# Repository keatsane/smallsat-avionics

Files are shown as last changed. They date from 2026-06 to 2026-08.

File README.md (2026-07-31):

# SmallSat Avionics SIL/HIL Testbed

A bench testbed for small-satellite avionics: STM32 firmware, portable C++ flight logic, and Python tooling for software- and hardware-in-the-loop testing.
Everything runs on a workbench with real parts and test gear: an STM32 as the flight computer, sensors and power hardware, a logic analyzer, and a scope. Behavior gets checked in software first (SIL), then on the hardware itself (HIL), and the results - logs, reports, and scope captures - land in the repo alongside the code.

## The stack
- STM32 firmware in C: bare-metal CMSIS drivers, timers, UART, sensors, watchdog.
- Flight logic in C++: spacecraft modes, fault detection, and safe-mode handling, written to run and be tested on a PC before reaching hardware.
- Python: test scenarios, fault injection, and report generation.

## Status
The mission loop works over radio, end to end: the vehicle - on bench power, no data cable - is commanded over a LoRa uplink into its pointing mode, captures an image, and downlinks it over a separate nRF24 payload link, where the ground station reassembles it and asks for whatever the air dropped. The lossy one-way payload link runs selective repeat: one full pass, then the ground names its missing chunks over the uplink and the vehicle resends exactly those out of the camera's own buffer.

The host flight software is unit-tested and runs a fourteen-scenario SIL suite: modes, faults, command validation, telemetry, recovery, degraded fallbacks, same-cycle response ordering, and closed-loop attitude scenarios against an in-repo plant model with measured inertias. The same C++ flight logic cross-compiles onto the STM32 behind a platform abstraction; the bare-metal side has SysTick timing, interrupt-driven UART across three USARTs, register-level SPI and I2C drivers for six devices, and the shared framed message codec in `common/protocol/`.

The OBC now runs a FreeRTOS task model rather than a super-loop: one control task owns the flight software at 10 Hz on an absolute wake-up, sensor sampling and health reporting run as their own tasks, and every task's state, check-in age, and stack high-water go out as telemetry at 1 Hz. An independent watchdog is serviced only when every task with a liveness deadline has checked in, and its bite has been demonstrated on the bench - the board resets and comes back reporting `reset=iwdg-watchdog`.

The first HIL slice is bench-verified: the board beacons live telemetry, the host runner detects link loss against the 5 s heartbeat timeout, and both HIL scenarios pass with scope-backed packet timing. The ICM-20948 IMU is also in the loop: accel/gyro plus AK09916 magnetometer samples go out as timestamped telemetry with per-half validity flags, and the sensor monitor turns invalid or frozen sources into the matching dropout faults. `ACCEL_GYRO_DROPOUT` is Degraded and can retreat POINTING/DETUMBLE to STANDBY; `MAG_DROPOUT` is a report-only Warning. INA228 power telemetry is live too - bus voltage, current, and power as timestamped, validity-flagged samples, sensed high-side on the main battery bus so the voltage reads state of charge; `POWER_DROPOUT` covers an invalid or missing sample. Structural temperature (TMP117) streams the same way, with overtemperature wired to SAFE and a report-only undertemperature.

The physical rig is built: a three-plate stack on a lazy-susan pivot, with the reaction wheel and its encoder below, the OBC and sensors in the middle, and the radios and status LEDs up top. The wheel runs closed-loop FOC against a real magnetic encoder, and stepping its speed visibly kicks the platform the other way - the reaction-wheel effect, on the bench. The whole stack runs off a 14.8 V bus through its own switch, shunt, and regulators.

The attitude layer runs on the platform even while the wheel's driver board is away for replacement: yaw comes from a gyro-integrated, magnetometer-anchored heading estimate (the compass self-calibrates its hard iron and even its sign, live, against the gyro), DETUMBLE enters autonomously when the platform is spun and hands back whatever mode it interrupted, and a commanded bearing survives mode changes. The ground segment is its own node: an Adafruit Feather M0 with both receivers and two OLED status panels, compiling the satellite's own protocol headers, bridged to a Python console that decodes, files images, retries commands until acknowledged, and can fly the whole point-shoot-downlink-park sequence as one `shoot` command.

Remaining: the wheel driver's replacement board (closing the physical control loop, with HIL for the attitude requirements), the battery and its fuse (removing the last wires entirely), and the slew-and-image survey capstone.

## Layout
- obc/ - on-board computer firmware, STM32F446 board support (drivers, devices, FreeRTOS tasks)
- common/ - the wire contract: frame codec, message layouts, and the command/fault/mode id catalog
- docs/ - the written record: architecture, requirements, verification, hardware, and reports
- esc/ - reaction-wheel node firmware, SimpleFOC on the B-G431B-ESC1
- fsw/ - portable C++ flight software: modes, faults, commands, attitude control, with host unit tests, the SIL shim, and the plant model
- gsw/ - ground station firmware for the Feather M0: both receivers, the uplink, and the OLED panels
- tools/ - host-side Python: the ground console, SIL and HIL scenario runners, scope capture, over a shared ground library
- cad/ - Fusion 360 models for the printed frame, plates, and flywheel
- vendor/ - CMSIS, FreeRTOS, and ETL as submodules, plus checked-in OV2640 register tables

## Documentation

| Document | What is in it |
| --- | --- |
| [architecture.md](docs/architecture.md) | how the system is put together: the language split, the two comm links, the onboard buses, the FDIR pipeline, and the three-plate stack |
| [requirements.md](docs/requirements.md) | every requirement with its id, status, verification method, and the artifact that proves it |
| [verification.md](docs/verification.md) | the evidence ladder, the SIL and HIL harnesses, and the full scenario catalog |
| [setup.md](docs/setup.md) | prerequisites, building and flashing each node, and every test and tooling command |
| [bom.md](docs/bom.md) | the parts actually on the bench, with a vendored datasheet block for each |
| [hardware.md](docs/hardware.md) | the physical build: part constraints, bench tools, placement and keep-away rules, and the CAD layout |
| [wiring.md](docs/wiring.md) | the bench wiring sheet - connector by connector, pin by pin |
| [roadmap.md](docs/roadmap.md) | a working document: what is left to build, in order, and the design decisions behind it |
| [journal.md](docs/journal.md) | a working document: the dated log of what was built each session and how it went |
| [reports/](docs/reports) | generated SIL and HIL run reports, plus the scope-capture companions |

## License
Apache 2.0.

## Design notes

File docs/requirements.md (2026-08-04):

# Requirements

Running requirements for the avionics stack. Each requirement has an ID, a statement, a status, and a verification method (test, analysis, inspection, or demonstration); once there is evidence, the artifact is listed too. Requirements are written ahead of the code they govern, so many start as planned until their phase lands. The status, not the existence of the requirement, tracks reality: planned -> in progress -> unit-verified -> SIL-verified -> bench-verified -> HIL-verified. A requirement whose verification line lists methods beyond its current status still owes that evidence.

| Section | Covers |
| --- | --- |
| [Mode management](#mode-management) | the six modes, the legal transitions between them, and the transition log |
| [Fault management](#fault-management) | the detect - debounce - latch - respond pipeline, severities, and the degraded fallbacks |
| [Executive](#executive) | the once-per-cycle ordering, including which side wins a same-cycle conflict |
| [Comms - command uplink and telemetry downlink](#comms---command-uplink-and-telemetry-downlink) | command validation and acknowledgment, the heartbeat, and the command-loss timer |
| [Real-time execution and recovery](#real-time-execution-and-recovery) | the fixed-rate control cycle, task health, stack margins, and the watchdog |
| [Sensors and data validity](#sensors-and-data-validity) | validity flags, staleness, and disagreement between redundant sources |
| [Status indication](#status-indication) | the three-bead WS2812 array - mode, fault severity, and link health |
| [Attitude control (ADCS)](#attitude-control-adcs) | detumble and pointing against the reaction wheel |
| [Payload](#payload) | image capture, the camera dropout fault, and the chunked downlink |
| [Platform abstraction and portability](#platform-abstraction-and-portability) | the boundary that lets the same flight software run on the host and on the STM32 |
| [Verification and traceability](#verification-and-traceability) | the scenario harnesses and the requirement-to-artifact chain |

## Mode management

The spacecraft operates in exactly one of six modes at any time. Their intent:

| Mode | Purpose |
| ---- | --- |
| BOOT | power-on and self-checks |
| STANDBY | idle and healthy, awaiting commands |
| DETUMBLE | reduce body rates after deployment or upset |
| POINTING | hold a commanded attitude |
| DOWNLINK | empty the onboard data buffer to the ground during a contact pass |
| SAFE | minimal, power-conservative state after a critical fault |

**REQ-MODE-001** - The flight software shall represent the current operating mode as exactly one value of the set {BOOT, STANDBY, DETUMBLE, POINTING, DOWNLINK, SAFE} at all times.  
**Type**: Functional  
**Status**: unit-verified  
**Verification**: unit test  
**Artifact**: fsw/test/test_mode_manager.cpp

**REQ-MODE-002** - On power-on or reset, the flight software shall initialize the current mode to BOOT before permitting any transition, and have an empty log.  
**Type**: Functional  
**Status**: unit-verified  
**Verification**: unit test  
**Artifact**: fsw/test/test_mode_manager.cpp

**REQ-MODE-003** - The flight software shall permit only the autonomous mode transitions listed below. Any transition not listed - including a transition from a mode to itself - shall be treated as illegal.

| From | Legal transitions to |
| ---- | --- |
| BOOT | STANDBY, DETUMBLE, SAFE |
| STANDBY | DETUMBLE, POINTING, DOWNLINK, SAFE |
| DETUMBLE | STANDBY, POINTING, DOWNLINK, SAFE |
| POINTING | STANDBY, DETUMBLE, DOWNLINK, SAFE |
| DOWNLINK | STANDBY, DETUMBLE, POINTING, SAFE |
| SAFE | none autonomously (ground-commanded to STANDBY only - see REQ-MODE-006) |

The operating modes form a clique - each reaches every other. An earlier table forced sequencing hops (STANDBY could not reach POINTING without passing through DETUMBLE), which encoded a deployment story this bench rig does not have and cost a command per hop. What stays restricted is the frame of the graph: BOOT is left only by passing self-checks, SAFE only by ground command.

**Type**: Functional  
**Status**: unit-verified  
**Verification**: unit test  
**Artifact**: fsw/test/test_mode_manager.cpp

**REQ-MODE-004** - On a request for a transition that is not in the legal set, the flight software shall leave the current mode unchanged and shall not append a transition log entry.  
**Type**: Functional  
**Status**: SIL-verified  
**Verification**: unit test and SIL  
**Artifact**: fsw/test/test_mode_manager.cpp, docs/reports/sil/SIL-007.md

**REQ-MODE-005** - Every operating mode (BOOT, STANDBY, DETUMBLE, POINTING, DOWNLINK) shall have a legal transition to SAFE, so a fault response can command SAFE from any operating mode.  
**Type**: Functional  
**Status**: unit-verified  
**Verification**: unit test  
**Artifact**: fsw/test/test_mode_manager.cpp

**REQ-MODE-006** - The flight software shall perform no autonomous transition out of SAFE. The only permitted exit from SAFE shall be a ground-commanded transition to STANDBY.  
**Type**: Functional  
**Status**: SIL-verified  
**Verification**: unit test and SIL  
**Artifact**: fsw/test/test_mode_manager.cpp, docs/reports/sil/SIL-006.md

**REQ-MODE-007** - The flight software shall record, for every transition, the trigger that caused it, drawn from the set {PowerOn, Nominal, FaultEntry, FaultCleared, Timeout, Command}.  
**Type**: Functional  
**Status**: unit-verified  
**Verification**: unit test  
**Artifact**: fsw/test/test_mode_manager.cpp

**REQ-MODE-008** - On every accepted transition, the flight software shall append one record to the mode transition log containing: the platform timestamp in milliseconds, the trigger, the previous mode, the new mode, and the requirement ID the transition serves.  
**Type**: Functional  
**Status**: unit-verified  
**Verification**: unit test  
**Artifact**: fsw/test/test_mode_manager.cpp

**REQ-MODE-010** - The flight software shall leave BOOT autonomously, entering STANDBY once every fault detector has had a full debounce window to disqualify the vehicle and none has latched a Critical fault. The transition shall carry the Nominal trigger. BOOT shall never be a resting state: absent a Critical fault the vehicle proceeds, and given one it safes.  
**Type**: Functional  
**Status**: unit-verified  
**Verification**: unit test and SIL  
**Artifact**: fsw/src/executive.cpp, fsw/test/test_executive.cpp

The wait is deliberate rather than an immediate hop on the first cycle. A fault needs `debounce_n` consecutive bad samples to latch, so leaving BOOT any sooner would mean declaring the self-check passed before a persistently bad sensor could possibly have failed it.

**REQ-MODE-011** - The flight software shall exit DETUMBLE autonomously, entering STANDBY once the measured body rate has remained inside the controller's deadband for one second of consecutive samples. The transition shall carry the Nominal trigger. A sample outside the deadband shall reset the count.
**Type**: Functional
**Status**: SIL-verified (SIL-013 - the vehicle nulls a 1 rad/s spin and steps down on its own, with the Nominal trigger and this requirement id in the log row. SIL-011 ends before the exit can fire and still expects DETUMBLE, so the pair pins both halves: converge first, then leave)
**Verification**: SIL, then HIL once the wheel is back
**Artifact**: fsw/src/executive.cpp, docs/reports/sil/SIL-013.md

**REQ-MODE-012** - The flight software shall enter DETUMBLE autonomously from any operating mode other than SAFE and POINTING when the measured body rate exceeds a configured threshold for three consecutive samples, shall remember the interrupted mode, and shall return to it when the detumble completes. The transitions shall carry the Nominal trigger.
**Type**: Functional
**Status**: SIL-verified (SIL-014 - a 2.5 rad/s shove in STANDBY pulls the vehicle into DETUMBLE on its own and it resumes STANDBY when nulled; the resume of an interrupted DOWNLINK is unit-verified. The shove has to beat bearing friction to the threshold, which sheds ~2.9 rad/s per second on its own - on this rig autonomy only sees the upsets friction cannot handle first)

**POINTING is excluded, and the rig is why (2026-08-04).** A slew to a new bearing is body rate on purpose, and it passes the entry threshold long before it reaches the target - so the vehicle interrupted its own manoeuvre, detumbled the rate its own controller had asked for, resumed POINTING, and started again. The bench showed forty seconds of that without ever arriving. The rule underneath: this requirement answers rate *nobody asked for*. In POINTING the rate is the controller's own output, and bounding it belongs to the pointing law's damping term, not to a mode change that discards the target. SAFE is excluded for the older reason - a safed vehicle sheds activity, and spinning quietly is what SAFE already accepts.
**Verification**: unit test, SIL, then HIL once the wheel is back
**Artifact**: fsw/src/executive.cpp, fsw/test/test_executive.cpp, docs/reports/sil/SIL-014.md

**REQ-MODE-009** - The mode transition log shall be a fixed-capacity buffer that allocates no memory dynamically and retains at least the 32 most recent records; when full, the oldest record shall be overwritten.  
**Type**: Constraint  
**Status**: unit-verified  
**Verification**: unit test  
**Artifact**: fsw/test/test_mode_manager.cpp

## Fault management

Every fault carries a severity that drives its response:

| Severity | Response when latched |
| --- | --- |
| Warning | reported in telemetry; off-nominal but still fully capable; no failover |
| Degraded | a capability was lost but a documented fallback exists; switch to it and keep operating; does not force SAFE |
| Critical | a capability was lost with no fallback; forces SAFE if unresolved |

The live fault catalog (command-link loss, IMU dropouts, power-monitor dropout, undervoltage, overvoltage, and overcurrent) is defined once in `common/protocol/state.hpp`; a fault's position there is both its id and its bit in the active-fault bitmask. Planned future capabilities add their own faults when the detector code lands.

**REQ-FAULT-001** - The fault manager shall latch an active fault until it is explicitly cleared; a condition that clears on its own shall not un-latch the fault.  
**Type**: Functional  
**Status**: unit-verified  
**Verification**: unit test  
**Artifact**: fsw/test/test_fault_manager.cpp

**REQ-FAULT-002** - A latched Critical fault shall command SAFE, and only after its debounce window so a transient sample cannot force it.  
**Type**: Functional  
**Status**: bench-verified (the bench supply was walked down from 14.8 V; UNDERVOLTAGE latched at 13.6 V and the vehicle entered SAFE within one heartbeat, with the mode and fault beads following)  
**Verification**: unit test, SIL scenario (undervoltage -> SAFE), then a bench sweep  
**Artifact**: fsw/test/test_fault_manager.cpp, docs/reports/sil/SIL-001.md (scenario SIL-001), docs/journal.md

**REQ-FAULT-003** - Each fault shall have a defined policy - severity, debounce threshold, and owning requirement - held in a single fault table that is the only place fault policy is written; a compile-time check shall keep that table sized to the fault catalog.  
**Type**: Constraint  
**Status**: unit-verified  
**Verification**: inspection and unit test (compile-time size check)  
**Artifact**: fsw/src/fault_manager.cpp

**REQ-FAULT-004** - A fault shall latch only after its debounce threshold of consecutive bad samples is reached; a single transient bad sample shall never latch it.  
**Type**: Functional  
**Status**: SIL-verified  
**Verification**: unit test and SIL  
**Artifact**: fsw/test/test_fault_manager.cpp, docs/reports/sil/SIL-004.md

**REQ-FAULT-005** - A fault of Warning or Degraded severity shall not by itself command SAFE; a Degraded fault shall switch to its documented fallback behavior (see Degraded fallback behaviors below), and every such fault shall be latched and reported in telemetry.
**Type**: Functional
**Status**: SIL-verified (SIL-003 for the no-SAFE half; SIL-009 and SIL-010 for the retreats. The WHEEL_DROPOUT retreat is unit-verified only - same code path from the same two modes as the gyro retreat, so a third scenario would restate SIL-009 with one name changed)
**Verification**: unit test and SIL  
**Artifact**: fsw/src/executive.cpp, fsw/src/sensor_monitor.cpp, fsw/test/test_fault_manager.cpp, fsw/test/test_executive.cpp, fsw/test/test_sensor_monitor.cpp, docs/reports/sil/SIL-003.md, docs/reports/sil/SIL-009.md, docs/reports/sil/SIL-010.md

### Degraded fallback behaviors

REQ-FAULT-005 requires a Degraded fault to switch to its documented fallback - listed below - rather than forcing SAFE. A Warning fault such as `MAG_DROPOUT` latches and reports without changing mode.

| Fault | Fallback when latched |
| ----- | --- |
| ACCEL_GYRO_DROPOUT | In POINTING or DETUMBLE - the modes that depend on body-rate feedback - retreat to STANDBY, a stable idle; holding attitude without the gyro is unsafe, but the loss is not mission-ending. In any other mode, latch and report only. |
| POWER_DROPOUT | In POINTING, DETUMBLE, or DOWNLINK - the high-power modes - retreat to STANDBY; with the power monitor unreadable, running power-hungry operations blind to brownout/overcurrent is unsafe, and STANDBY's lower draw cuts the risk. In any other mode, latch and report only. |
| WHEEL_DROPOUT | In POINTING or DETUMBLE - the two modes that actuate - retreat to STANDBY; with the reaction wheel's link down a torque command goes nowhere, so holding a mode the rig cannot fly is a false claim of control. In any other mode, latch and report only. |

The active retreats - POINTING/DETUMBLE -> STANDBY on ACCEL_GYRO_DROPOUT and on WHEEL_DROPOUT, and POINTING/DETUMBLE/DOWNLINK -> STANDBY on POWER_DROPOUT - run in the executive's fault-response step and are logged as `FaultEntry` transitions stamped REQ-FAULT-005. Recovery is ground-commanded like every fault (CLEAR_FAULT, REQ-FAULT-010); the planned RESET_DEVICE command will let the ground re-initialize the affected sensor before clearing it.

`WHEEL_DROPOUT` is detected from the silence on the wheel link rather than from a sample: the ESC beacons its status every 250 ms, so a second without one is a dead link. The first frame after boot gets a longer window (8 s) because the ESC aligns its FOC for about five seconds from cold and says nothing until it finishes - without that grace every boot would latch a dropout that clears itself a moment later, which is how a real fault gets trained into background noise. An ESC that never comes up still latches once the grace expires.

**REQ-FAULT-006** - The flight software shall evaluate the full fault set once per control cycle and apply the required response; when more than one response is indicated, the most conservative one shall win (SAFE dominates).  
**Type**: Functional  
**Status**: unit-verified  
**Verification**: unit test and SIL  
**Artifact**: fsw/test/test_fault_manager.cpp

**REQ-FAULT-007** - The flight software shall define the fault catalog once, in common/protocol/state.hpp, as a single index enum; a fault's position in that list shall be both its id and its bit position in the active-fault bitmask.  
**Type**: Interface  
**Status**: unit-verified  
**Verification**: inspection  
**Artifact**: common/protocol/state.hpp

**REQ-FAULT-008** - The set of currently latched faults shall be exposed as a bitmask (bit n set when fault id n is latched); this bitmask is what the heartbeat carries (see REQ-TLM-002).  
**Type**: Interface  
**Status**: unit-verified  
**Verification**: unit test  
**Artifact**: fsw/test/test_fault_manager.cpp

**REQ-FAULT-009** - A good (healthy) sample shall reset a fault's consecutive-bad-sample count, but shall not clear a fault that has already latched (see REQ-FAULT-001).  
**Type**: Functional  
**Status**: SIL-verified  
**Verification**: unit test and SIL  
**Artifact**: fsw/test/test_fault_manager.cpp, docs/reports/sil/SIL-004.md

**REQ-FAULT-010** - A latched fault shall be cleared only by an explicit action - a ground command or a defined recovery sequence - never autonomously by the flight software.  
**Type**: Functional  
**Status**: SIL-verified  
**Verification**: unit test and SIL  
**Artifact**: fsw/test/test_fault_manager.cpp, fsw/test/test_executive.cpp, docs/reports/sil/SIL-006.md

**REQ-FAULT-011** - The fault manager shall maintain a time-ordered log of fault state-change events; each entry shall record the platform timestamp, the fault id, and whether the fault latched or cleared. Only edges shall be logged - never per-sample - and the log shall be a fixed-capacity ring that overwrites its oldest entry when full.  
**Type**: Functional  
**Status**: unit-verified  
**Verification**: unit test  
**Artifact**: fsw/test/test_fault_manager.cpp

**REQ-FAULT-012** - It shall be possible to inhibit an individual fault's autonomous response for ground testing. An inhibited fault shall still debounce, latch, log, and report in telemetry; only the mode change it would command shall be suppressed. The inhibited set shall be reported, so that a run with inhibits in force cannot be mistaken for one without.  
**Type**: Functional  
**Status**: unit-verified (compile-time inhibit list declared at the platform boundary, announced in the boot banner, and carried in every heartbeat; ground-commandable inhibits wait on the ground station in Phase 8)  
**Verification**: unit test  
**Artifact**: fsw/src/fault_manager.cpp, fsw/src/executive.cpp, fsw/test/test_fault_manager.cpp, fsw/test/test_comms.cpp, common/protocol/msg.hpp, tools/ground/frames.py

Inhibits exist because the bench rig is routinely missing subsystems the flight configuration assumes: with no ground station, COMMAND_LINK_LOSS safes the vehicle about five seconds after every boot. Suppressing the *response* while keeping the *evidence* is the standard fault-protection inhibit used during spacecraft commissioning, and it is why the fault still appears in every heartbeat. WHEEL_DROPOUT was inhibited alongside it while the ESC was out of the stack; it came off on 2026-08-03 when the replacement board joined the link, which is the list working as intended - an inhibit is meant to be retired by hardware arriving, not to become permanent.

The inhibited set rides in the heartbeat as its own bitmask, in the same bit layout as the active-fault mask. Announcing it once in the boot banner is not enough: a console attached mid-run, or a log read later, shows two latched faults with the banner long out of scrollback and nothing on the wire saying their responses were suppressed. The status array distinguishes them by colour, but only to someone in the room. Carrying it in telemetry is what makes a saved log self-describing.

## Executive

**REQ-EXEC-001** - The flight software shall process each control cycle's inputs in a fixed, documented order: fault-sample ingestion, command validation, fault response, command dispatch. The fault response shall take precedence: a command accepted in the same cycle a critical fault forces SAFE shall not override the SAFE entry. Command acceptance acknowledges validation only; execution outcome is observed through telemetry. Validation is expected to reject what it can already determine is impossible, including an unreachable SET_MODE target (REQ-CMD-006) - what acceptance cannot promise is immunity from a fault response raised later in the same cycle.  
**Type**: Functional  
**Status**: SIL-verified  
**Verification**: unit test and SIL  
**Artifact**: fsw/src/executive.cpp, fsw/test/test_executive.cpp, docs/reports/sil/SIL-008.md

## Comms - command uplink and telemetry downlink

**REQ-CMD-001** - The flight software shall validate every command - known id, in-range parameters, and legal in the current mode - before acting on it; an invalid command shall be rejected and reported, never executed.  
**Type**: Functional  
**Status**: SIL-verified (the uplink path onto the OBC is written - both links are drained each cycle and decoded commands enter as cycle inputs - but has not been exercised on the bench, so validation remains host-only evidence)  
**Verification**: unit test and SIL  
**Artifact**: fsw/test/test_comms.cpp, obc/Src/main.cpp, tools/uart_monitor.py, docs/reports/sil/SIL-002.md (scenario SIL-002)

**REQ-CMD-002** - Loss of ground command contact for longer than a defined timeout shall raise COMMAND_LINK_LOSS.  
**Type**: Functional  
**Status**: SIL-verified  
**Verification**: unit test and SIL  
**Artifact**: fsw/test/test_comms.cpp, docs/reports/sil/SIL-005.md

**REQ-CMD-005** - BOOT shall not be a commandable mode. A SET_MODE request naming BOOT shall be rejected as a bad argument.  
**Type**: Functional  
**Status**: unit-verified  
**Verification**: unit test  
**Artifact**: fsw/src/comms/command_handler.cpp, fsw/test/test_comms.cpp

**REQ-CMD-006** - A SET_MODE request naming a mode that is not reachable from the current mode shall be rejected as illegal-in-mode at validation, rather than accepted and then refused by the mode manager.  
**Type**: Functional  
**Status**: SIL-verified  
**Verification**: unit test and SIL  
**Artifact**: fsw/src/comms/command_handler.cpp, fsw/test/test_comms.cpp, docs/reports/sil/SIL-007.md

This extends REQ-CMD-005's reasoning from one mode to the whole transition table: an acknowledgement that says yes while the vehicle does not move is a worse interface than a refusal that names why. It narrows REQ-EXEC-001 rather than contradicting it - acceptance still is not execution, because a safing raised in the same cycle overrides an accepted command (SIL-008). What changed is that a refusal already knowable at validation time is now reported at validation time.

BOOT means "powered on and still self-checking" - a state the vehicle enters by resetting and leaves by passing its checks (REQ-MODE-010). There is nothing for the flight software to do with a request to re-enter it. Validating it away matters because the alternative is worse than useless: `BOOT` is a real mode id and a legal transition target from nowhere, so without this check the command passes validation, is acknowledged as accepted, and then changes nothing - an ack that says yes while the vehicle does not move.

**REQ-CMD-003** - Every command shall be acknowledged in telemetry as accepted or rejected, with a reason given on rejection. A command repeating the previous sequence number shall be answered with the previous verdict and shall not be executed again.  
**Type**: Functional  
**Status**: SIL-verified (both verdicts observed as decoded telemetry frames; the retransmission rule is unit-verified. HIL still owed)  
**Verification**: unit test (ack construction, retransmission), SIL and HIL  
**Artifact**: fsw/test/test_comms.cpp, docs/reports/sil/SIL-002.md (scenario SIL-002)

The retransmission rule exists because the ground resends: the LoRa link is half duplex, the vehicle cannot hear anything while its own beacon is on the air, and a command sent into that window is simply not received. The ground console retransmits until it sees an ack, which means a command whose *ack* was lost arrives twice - so the vehicle answers the second copy without acting on it.

**REQ-CMD-004** - Every handled command shall be appended to a command event log recording the platform timestamp, the command id, the verdict, and the rejection reason. The log shall be a fixed-capacity ring that allocates no memory dynamically and overwrites its oldest entry when full.  
**Type**: Functional  
**Status**: unit-verified  
**Verification**: unit test  
**Artifact**: fsw/test/test_comms.cpp

**REQ-TLM-001** - All telemetry shall be framed with a sync header, message id, length, and CRC-16; a corrupted or mis-framed packet shall be detected and discarded, never acted on.  
**Type**: Interface  
**Status**: HIL-verified (live framing on the real wire, every frame CRC-checked with zero rejects over the window; the discard path itself is unit-verified)  
**Verification**: unit test and HIL  
**Artifact**: common/protocol/frame.cpp, fsw/test/test_comms.cpp, docs/reports/hil/HIL-001.md, docs/reports/hil/HIL-001-scope.md

**REQ-TLM-002** - The flight software shall emit a periodic heartbeat carrying uptime, a sequence number, the current mode, and the active-fault bitmask.  
**Type**: Functional  
**Status**: HIL-verified (1 Hz emission decoded live from the STM32 and timed on the scope; the on-wire frame carries real mode and fault state)  
**Verification**: unit test, SIL and HIL  
**Artifact**: fsw/test/test_comms.cpp, docs/reports/sil/SIL-001.md, docs/reports/hil/HIL-001.md, docs/reports/hil/HIL-001-scope.md

**REQ-TLM-003** - The heartbeat sequence number shall increment monotonically so the ground can detect dropped packets.  
**Type**: Functional  
**Status**: HIL-verified (59 consecutive live periods with zero gaps; a board reset is detected as a sequence discontinuity in HIL-002)  
**Verification**: unit test; demonstration (scope/host decode)  
**Artifact**: fsw/test/test_comms.cpp, docs/reports/hil/HIL-001.md, docs/reports/hil/HIL-002.md

**REQ-TLM-004** - The telemetry transport shall be swappable behind the frame format - UART first, radio later - with no change to the wire format.  
**Type**: Constraint  
**Status**: demonstrated untethered (2026-07-30 - the vehicle on bench power with no data cable attached: commanded into POINTING over LoRa, a capture and a downlink over the nRF24, 137 chunks reassembled to `captures/image_0017.jpg` with intact JPEG markers. The first pass delivered 72% and two selective-repeat rounds named and refilled the rest, which is the point of the protocol: delivery variance stopped mattering. One encoded frame crosses four transports unchanged; LoRa carries heartbeats, acks and attitude only - the full stream would want 2.8 s of air time per second)
**Verification**: inspection and HIL  
**Artifact**: common/protocol/frame.cpp (the format, unchanged per transport), fsw/platform/stm32/platform_stm32.cpp (one call, three transports), obc/Src/devices/rfm95.c, obc/Src/freertos/telemetry_task.cpp, obc/Src/drivers/uart.c

**REQ-TLM-006** - The ground shall be able to request a single frame of a named telemetry kind over the low-rate link. The full sensor stream shall not ride that link.
**Type**: Functional
**Status**: demonstrated over the air (2026-07-31 - `poll POWER` from the ground console returned one POWER frame over the beacon, on battery power with no cable: bus 16.68 V, 108 mA. The stream restriction is arithmetic: the full stream wants ~2.8 s of air time per second of flight)
**Verification**: unit test, then demonstration over the radio
**Artifact**: fsw/src/executive.cpp, fsw/test/test_executive.cpp, obc/Src/freertos/telemetry_task.cpp

**REQ-TLM-005** - The spacecraft shall indicate current mode, worst latched fault severity with a count of latched faults, and command-link state on a local status display, carrying the same information as the heartbeat packet so the two can be read against each other.  
**Type**: Functional  
**Status**: bench-verified (2026-07-30 - two faults latched and inhibited, the bead held blue and winked twice per cycle against a heartbeat naming exactly those two. Inhibited faults are counted: they are latched, which is what the requirement asks)  
**Verification**: demonstration (drive each mode, latch faults of each severity, and drop the uplink; observe the display against the decoded heartbeat)  
**Artifact**: obc/Src/freertos/control_task.cpp, obc/Src/devices/ws2812.c

## Real-time execution and recovery

**REQ-RT-001** - The flight software shall maintain a monotonic millisecond time base, used to timestamp every logged event.  
**Type**: Performance  
**Status**: bench-verified  
**Verification**: demonstration and inspection  
**Artifact**: obc/Src/drivers/systick.c, obc/Src/freertos/control_task.cpp (passes millis into each cycle)

**REQ-RT-002** - The decision paths shall run at a fixed, bounded rate and shall allocate no memory dynamically (fixed-capacity containers only).  
**Type**: Constraint  
**Status**: HIL-verified (HIL-003: 59 heartbeat periods, mean 1.000 s, the spread host-side USB jitter. The super-loop it replaced was a structural 2% slow. The rate held through a 128-chunk downlink with no cycle overrunning - the worst is the one a capture completes on, where the JPEG end-marker scan costs ~16 ms of 100. Static allocation only)  
**Verification**: inspection and analysis, plus HIL (measure heartbeat spacing idle and under downlink load)  
**Artifact**: fsw/include/fsw/inputs.hpp and fsw/include/fsw/fault_manager.hpp (fixed-capacity ETL containers, no heap), `configSUPPORT_DYNAMIC_ALLOCATION 0` in obc/Inc/FreeRTOSConfig.h, the control task's `xTaskDelayUntil` in obc/Src/freertos/control_task.cpp, docs/reports/hil/HIL-003.md

**REQ-RT-003** - Under concurrent workloads the flight software shall run as prioritized tasks with the control loop at the highest priority, and shall report task health (liveness and stack high-water).  
**Type**: Performance  
**Status**: HIL-verified (HIL-003, 60 s untouched: every task present in all 60 reports, watchdog fed on all of them, worst stack margin 104 free words against a 64 floor. Stacks are sized at ~2.5x measured peaks - generous rather than tight, because the kernel's high-water figure counts a fill pattern and reads optimistic when a written byte happens to hold it)  
**Verification**: HIL (scheduler-smoke run)  
**Artifact**: the task table in obc/Inc/rtos_tasks.h; obc/Src/freertos/; `task_health_t` in common/protocol/msg.hpp; docs/reports/hil/HIL-003.md
**Artifact**: the task table in obc/Inc/rtos_tasks.h; obc/Src/freertos/; `task_health_t` in common/protocol/msg.hpp with its ground decoder and 6 pytest cases

**REQ-RT-004** - An unhandled processor fault exception (hard fault, memory-management, bus, or usage fault) shall be caught by a dedicated handler that captures the fault context and performs a controlled reset, rather than leaving the processor halted in a default infinite loop.  
**Type**: Functional  
**Status**: bench-verified (forced a fault on the bench with a `udf` undefined instruction; the handler dumped pc=0x0800320c, CFSR=0x00010000 (UFSR.UNDEFINSTR) and HFSR=0x40000000 (FORCED - escalated to HardFault), then rebooted via NVIC_SystemReset, the next boot reading reset=software)  
**Verification**: demonstration (trigger a fault, observe the capture then reset)  
**Artifact**: obc/Src/drivers/fault.c

**REQ-WDG-001** - An independent hardware watchdog shall reset the on-board computer if the flight software stops servicing it within the watchdog window.  
**Type**: Functional  
**Status**: HIL-verified (service: HIL-003 fed the watchdog in all 60 reports of a 60 s window, each gated on every deadline task checking in. Bite: withholding the control task's check-in reset the board, and the next banner read `reset=iwdg-watchdog`. The withheld pet appears in telemetry first, which is what makes the reset attributable)
**Verification**: HIL (demonstrated reset)  
**Artifact**: obc/Src/drivers/iwdg.c, obc/Src/freertos/health_task.cpp

**REQ-WDG-002** - After any reset the flight software shall report the reset cause - including a watchdog reset - in a boot telemetry packet.  
**Type**: Functional  
**Status**: bench-verified (2026-07-30 - a cold start emitted exactly one `BOOT t=1125 ms reset=POWER_ON clk=180000000 Hz` frame, decoded from the packet rather than read off the banner. It crosses the PAL as a first-cycle input, not a side channel. Pin reset and watchdog reset were each demonstrated on the banner)  
**Verification**: HIL  
**Artifact**: obc/Src/drivers/reset.c, obc/Inc/drivers/reset.h, obc/Src/freertos/control_task.cpp, common/protocol/msg.hpp, tools/ground/frames.py

## Sensors and data validity

**REQ-SNS-001** - Every sensor sample shall be tagged with an acquisition timestamp and a validity flag; the flight software shall never use a sample marked invalid.  
**Type**: Functional
**Status**: bench-verified (the IMU sample carries an acquisition timestamp and per-half validity flags, streaming live on the bench; the sensor monitor treats an invalid half as a dropout rather than consuming it - a full attitude consumer that honors the flag lands with ADCS)
**Verification**: unit test and HIL
**Artifact**: common/protocol/msg.hpp (imu_data_t), obc/Src/devices/icm20948.c, fsw/src/sensor_monitor.cpp, fsw/test/test_sensor_monitor.cpp

**REQ-SNS-002** - A sensor whose data is invalid, missing, or frozen beyond a defined staleness window shall raise that sensor's dropout fault.
**Type**: Functional
**Status**: unit-verified (dropouts raised on invalid or frozen sources. Both invalid-source paths are bench-exercised: pulling the IMU latches ACCEL_GYRO_DROPOUT + MAG_DROPOUT, and POWER_DROPOUT latched while the INA228 was unreachable. **Owed: HIL**)
**Verification**: unit test and HIL
**Artifact**: fsw/src/sensor_monitor.cpp, fsw/test/test_sensor_monitor.cpp

**REQ-SNS-003** - Where redundant sources exist, disagreement beyond a defined threshold shall raise a dedicated disagreement fault added with that redundant sensor path.  
**Type**: Functional  
**Status**: deferred - conditional, and its condition is not met. The requirement is written to fire "where redundant sources exist" and this build has none: one IMU, one power monitor, one temperature sensor, one camera. Deliberately kept rather than deleted, because it is the rule any second sensor arrives under; deliberately not "planned", because planned implies work is queued and nothing here is buildable until a redundant path exists.  
**Verification**: unit test and SIL, when a redundant path exists

**REQ-SNS-004** - A valid monitored power reading outside its configured operating limits shall raise the corresponding power fault (undervoltage, overvoltage, overcurrent).
**Type**: Functional
**Status**: unit-verified; **HIL not planned** (2026-08-04). Each power fault is raised when its reading crosses the configured limit after debounce. An earlier bench run latched UNDERVOLTAGE live against the low-side monitor, but it has since moved high-side onto the 14.8 V bus and the limits were retuned, so that evidence does not cover this build.

Re-running it was considered and declined, for reasons worth stating rather than leaving as a gap. **Overcurrent cannot be tested at all here**: tripping 1.5 A needs a load bank the bench does not have, and the vehicle's own draw never approaches it. **Undervoltage and overvoltage would require disconnecting the flight battery and rigging a variable supply in its place**, which is bench work with a real chance of disturbing a rig that currently flies. The fault logic itself is exercised every run by the unit suite and by SIL-001, which drives an undervoltage to SAFE; what is missing is only the ADC-to-fault path on this specific wiring, and that is a narrower claim than the requirement being unverified.
**Verification**: unit test and HIL
**Artifact**: fsw/src/sensor_monitor.cpp, fsw/test/test_sensor_monitor.cpp

**REQ-SNS-005** - A valid monitored temperature reading outside its configured operating limits shall raise the corresponding temperature fault (overtemperature, undertemperature).
**Type**: Functional
**Status**: unit-verified; **HIL not planned** (2026-08-04). Both crossings latch after debounce, TEMP_DROPOUT on an invalid sample. Overtemperature is Critical -> SAFE; undertemperature is a report-only Warning, since a low-power state would only cool the spacecraft further.

Forcing a real crossing means heating the TMP117 to 60 C while it sits on a plate of PLA next to the flight electronics. A heat gun does that to more than the sensor, and risking a working vehicle to demonstrate a threshold comparison the unit tests already cover is a poor trade. Declined deliberately rather than left owed.
**Verification**: unit test and HIL
**Artifact**: fsw/src/sensor_monitor.cpp, fsw/test/test_sensor_monitor.cpp

## Status indication

**REQ-HMI-001** - The spacecraft shall indicate its current mode, the worst active fault severity, and its command-link health on an external visual indicator, updated every control cycle and readable without a ground connection.  
**Type**: Functional  
**Status**: bench-verified (three WS2812 beads from PA8 by TIM1_CH1 + DMA: mode by colour, the fault ladder, and the uplink as blinking amber before first contact, green in contact, red past the 5 s timeout. Bit timing scope-confirmed at 0.4/0.8 us on a 1.25 us period)
**Verification**: demonstration (observe the array follow a commanded mode change and a latched fault)  
**Artifact**: obc/Src/drivers/pwm_dma.c, obc/Src/devices/ws2812.c, obc/Src/main.cpp, docs/journal.md (the dated observation)

### Mode bead colors

Bead 0 carries the mode, one color each, no blinking - a spinning platform is read at a glance and a blink code is not.

**Motion is deliberately rationed across the strip.** Bead 1 spends it on a number (the latched-fault count) and bead 2 spends it on one persistent state (never-acquired). Nothing else blinks, and that is a decision rather than an omission: a strip where every bead moves cannot be counted, and the count is the only thing here carrying data rather than a category. DOWNLINK was considered for a mode blink and rejected - since the payload downlink became self-pacing a whole image leaves in about a second, so the blink would be over before anyone looked up.

| Mode | Color |
| ---- | ----- |
| BOOT | white |
| STANDBY | green |
| DETUMBLE | blue |
| POINTING | cyan |
| DOWNLINK | magenta |
| SAFE | red |

Bead 2 carries the uplink in three states: **blinking amber** before any command has ever arrived, **green** once the ground is in contact, **red** once the link has been silent past its 5 s timeout. Amber is a real distinction rather than a hedge - an un-latched loss fault before first contact only means the dead-man timer has not expired yet, which is unknown, not healthy - and it blinks because it is a state the rig sits in for a whole session, where a slow blink reads as searching and a steady amber reads as something settled.

**The bead asks the link, not the fault's response** (corrected 2026-07-30). It used to read `response_active(COMMAND_LINK_LOSS)`, which is false while the fault is inhibited - and the bench build inhibits it. The effect was that the bead went green on the first command ever received and stayed green for the rest of the session however long the ground had been gone. Suppressing a response is a decision about safing and says nothing about the link, so the display asks `link_lost()` directly. There is deliberately no fourth state for "silent but still inside the timeout": nothing keeps the link alive between typed commands, so that would be the normal condition during ordinary bench use and would blink continuously.

The whole array runs at level 4 of 255. The beads sit behind printed plastic and bleed through the walls at anything brighter, and 4 is the floor: the mixed colors set one channel to a fraction of it, and below that there are not enough steps left to hold the hue.

### Fault bead ladder

Bead 1 shows the worst rung that applies, highest first:

| Rung | Color | Meaning |
| ---- | ----- | --- |
| Critical | red | a latched Critical fault whose response is live - the vehicle is safing or has safed |
| Degraded | orange | a latched Degraded fault - a capability was lost and a documented fallback is in force |
| Warning | yellow | a latched Warning fault - off-nominal, reported only |
| Inhibited | blue | something is latched but every latched fault has its response inhibited (REQ-FAULT-012) |
| Clean | off | nothing latched |

An inhibited fault is deliberately excluded from the three alarm rungs and collected into the one below them. It remains in the heartbeat and in the boot banner, so nothing is hidden - but a bench build routinely runs with subsystems absent, and letting those hold the bead red on every boot is how a red indicator stops carrying information. Blue sits outside the red/orange/yellow alarm family on purpose: it reads as status, not as a call to act.

## Attitude control (ADCS)

**REQ-ADCS-001** - In DETUMBLE the flight software shall command the reaction wheel to reduce the measured body rate below a defined threshold.  
**Type**: Functional  
**Status**: **working on the rig (2026-08-04)** - a hand-spun platform pulls itself into DETUMBLE, the rate collapses to the deadband, and the vehicle steps back out on its own, repeatably and over the radio. Torques sit at 8-9 mN m against the 50 mN m ceiling. SIL-011 nulls a 2 rad/s spin in the model. Proportional rate feedback, no integral: against stiction an integral winds up while the platform is stuck and overshoots when it breaks loose.

The gain is the rig's, not the model's. At the modelled 0.02 N m per rad/s the loop commanded more torque than the bearing's breakaway and kicked the platform loose in alternating directions - a stick-slip limit cycle at ~90 deg/s that the model never showed, because the model's breakaway friction was a guess. 0.008 is what the bench accepts.

**The controller does about two and a half times what friction does (A/B, 2026-08-04).** "It stopped" is not proof on a platform that stops itself, so the same spin was run twice at 10 Hz on the wired link: in SAFE, where no torque is commanded and autonomous entry is disabled, and in STANDBY, where the spin pulls the vehicle into DETUMBLE. Both runs are checked in under `docs/data/` and graded by `tools/overlay.py`, which measures the arrest - the last unbroken run of falling rate - rather than the whole window, because a hand-spun run has a plateau in it while the platform is still being pushed and averaging that in halves the answer.

Friction alone shed the rate at **161 deg/s^2**; with the controller, **412 deg/s^2**. The peak commanded torque was 13 mN m, which against the measured platform inertia predicts ~164 deg/s^2 of additional deceleration against the ~250 observed - consistent within what an unmeasured `kOhmsPerKt` can account for, and pointing the same way as every other estimate of it. The measurement needs the control-rate telemetry: at the heartbeat's 1 Hz the whole decay is a single sample.  
**Verification**: SIL (single-axis plant model) and HIL (reaction-wheel rig)  
**Artifact**: fsw/src/attitude_control.cpp, fsw/test/test_attitude_control.cpp, fsw/sil/plant.cpp, fsw/sil/scenarios/sil_011_detumble.yaml, docs/reports/sil/SIL-011.md

**REQ-ADCS-002** - In POINTING the flight software shall hold a commanded single-axis attitude within a defined error band.  
**Type**: Functional  
**Status**: **working on the rig for small slews (2026-08-04)** - commanded to a bearing 28 degrees away, untethered and over the radio, the platform converged monotonically and settled at **0.7 degrees of error against a 2.9 degree band**, then held. No overshoot.

Two things about how it gets there, both properties of this plant rather than of the software:

**It is a cascade, not a PD on angle.** The original law asked for torque proportional to heading error, and at `k_angle = 0.4` a 7 degree error already demanded the wheel's entire ceiling - so POINTING was a relay, not a controller, and the rig answered with 130 deg/s slams and 19 degrees of overshoot. The outer loop now turns heading error into a *slew rate* bounded well inside the wheel's momentum budget, and the inner loop is REQ-ADCS-001's law with that rate as its setpoint. Detumble is the same equation with a setpoint of zero, which is why both modes share one sign convention and one measured gain.

**It inches rather than sweeping, and that is correct here.** At the stable gain the feedback asks for ~2 mN m and the bearing does not let go until several times that, so a fixed feedforward supplies the shove, applied only while the platform is stopped. Break loose, move, push drops out, friction stops it, repeat. Smooth rotation would need sustained torque above kinetic friction while staying under the gain that oscillates, and on this bearing those two windows do not overlap. A vehicle in free fall has no bearing and no stiction; the stepping is an artifact of testing attitude control on a lazy susan, and it is the honest limit of the rig rather than of the flight software.

The feedforward is now sized against a measurement rather than a bound: **breakaway is 5 mN m**, taken 2026-08-04 by the vehicle pulsing its own wheel at rising torque over the radio with nothing plugged into it (`PULSE_WHEEL`, and the `breakaway` console macro that drives it). The 8 mN m feedforward clears it by 1.6x. **Owed**: larger slews are untested and are expected to run the wheel out of momentum, which is REQ-ADCS-003's territory.  
**Verification**: SIL (single-axis plant model) and HIL (reaction-wheel rig)  
**Artifact**: fsw/src/attitude_control.cpp, fsw/test/test_attitude_control.cpp

**REQ-ADCS-003** - Actuator commands shall be saturation-limited, and sustained saturation shall raise a dedicated actuator fault added with the actuator-control path.  
**Type**: Functional  
**Status**: SIL-verified, both halves (SIL-012, 9/9). The limit half: the controller clamps and reports that it clamped, and SIL-011 stays inside the wheel's rate limit. The fault half: `WHEEL_SATURATED` latches at 90% of the wheel's measured top speed after a second of debounce, retreats the steering modes to STANDBY as a Degraded fallback, and STANDBY unwinds the wheel.

**The rig is what made this concrete.** Commanded 90 degrees under the old relay law, the platform travelled about 28 and stopped dead, holding full commanded torque with the rate at zero for fifteen seconds - the wheel at its speed limit, delivering nothing, and no telemetry saying so. The budget explains it: `j_wheel * wheel_rate_max` is 3.9e-3 kg m^2/s, which against the platform is 0.87 rad/s of body rate in total, and any sustained push exceeds that in well under a second.

**The recovery is the interesting half.** A wheel that cannot be desaturated has no cure, and a fault with no responder is a catalog entry - so the fault landed with momentum dumping rather than before it. A real spacecraft dumps against magnetorquers or thrusters; this one dumps against its own bearing. Any torque under the platform's breakaway spins the wheel down without moving the body at all, so the stiction that makes pointing hard on this rig is exactly what makes the wheel rechargeable. Dumping runs in STANDBY only - DETUMBLE and POINTING are steering and must not have their actuator drained underneath them - which is also why the fallback retreats *to* STANDBY: the retreat is where the cure lives, not a parking space. The fault stays latched for the ground to clear (REQ-FAULT-010), because a vehicle that silently re-arms hides how often it ran out.

**Owed: HIL.** The dump is verified against the plant model, not the rig, and it rests on the platform's breakaway being above the dump torque - measured at 5 mN m commanded against a 3 mN m dump.  
**Verification**: unit test and HIL  
**Artifact**: fsw/src/attitude_control.cpp, fsw/test/test_attitude_control.cpp, fsw/sil/scenarios/sil_012_pointing_saturation.yaml, docs/reports/sil/SIL-012.md

## Payload

**REQ-ADCS-004** - The ground shall be able to command the bearing held in POINTING, and the flight software shall report the held bearing, the commanded bearing, and the measured rate as telemetry.  
**Type**: Functional  
**Status**: **demonstrated over the radio (2026-08-04)** - `SET_HEADING 30` was commanded from the ground station with no cable on the vehicle, and the attitude telemetry showed the target, the heading closing on it, and the error settling inside the band. `SET_HEADING` carries a binary angle - one byte spanning a full turn, 1.4 degrees a step, which is why a commanded 30 reads back as 29.5 - and `attitude_status_t` reports heading, target, rate and commanded torque. It now goes out every control cycle rather than at the heartbeat's rate, because a 10 Hz loop cannot be judged from 1 Hz samples; the beacon decimates it back to once a second so the air-time budget is unchanged. The bearing is relative to POINTING entry, which is the only frame this vehicle can honestly offer while the wheel's magnets hold the magnetometer off.  
**Verification**: unit test and HIL  
**Artifact**: fsw/test/test_comms.cpp, fsw/src/executive.cpp

**REQ-PAY-001** - An accepted CAPTURE_IMAGE command shall start a payload image capture without blocking the control cycle; the capture outcome shall be reported in telemetry rather than returned to the command.  
**Type**: Functional  
**Status**: bench-verified (CAPTURE_IMAGE accepted in POINTING, the frame taken without a missed control cycle, and the result downlinked intact)  
**Verification**: unit test and HIL  
**Artifact**: fsw/src/executive.cpp, obc/Src/devices/ov2640.c, fsw/test/test_executive.cpp

**REQ-PAY-002** - Loss of the payload camera shall raise CAMERA_DROPOUT; the payload is not required for vehicle safety, so the fault shall latch and report without changing mode.  
**Type**: Functional  
**Status**: bench-verified (SPI3 harness pulled on a live board: CAMERA_DROPOUT latched within one heartbeat, the vehicle held STANDBY, reconnect and reset came up clean. The harness is shared, so this shows the fault path rather than isolating the camera)  
**Verification**: unit test and HIL  
**Artifact**: fsw/src/sensor_monitor.cpp, fsw/test/test_sensor_monitor.cpp, docs/wiring.md (the ungrounded-camera mechanism found by this test)

**REQ-PAY-003** - A captured frame shall be held in the camera's own buffer and read out in caller-sized chunks, so that no image-sized buffer is allocated in flight-software RAM.  
**Type**: Constraint  
**Status**: bench-verified (a 7299-byte frame drained to exactly its reported length, FF D8 to FF D9, through a 64-byte stack buffer). The per-chunk burst close is verified by use rather than by a dedicated re-test: the 2026-07-30 over-the-air images reassembled with intact markers through per-chunk closes, rewinds, and selective-repeat sweeps of the same fifo, which is the read-pointer-survives-deselect evidence that was owed  
**Verification**: inspection and HIL  
**Artifact**: obc/Src/devices/ov2640.c

**REQ-PAY-004** - In DOWNLINK the flight software shall direct the payload buffer to be emptied to the ground, and the platform shall do so in chunks at a rate bounded by the link and without blocking the control cycle. Each chunk shall identify its image, its index, and the total count, so that a contact pass ending mid-image leaves a resumable set of chunks rather than an unusable partial stream.  
**Type**: Functional  
**Status**: bench-verified over the air (2026-07-30: an 800x600 capture reassembled to a 22240-byte file with intact markers). The fsw signals whether to downlink and the platform paces it - the chunks-per-cycle bound was a link property sitting on the wrong side of the PAL. Lost chunks are recovered by selective repeat: the image goes out once, the ground names its gaps over the LoRa uplink (`chunk_request_t`), and the vehicle resends exactly those from the frame still held in the camera's fifo  
**Verification**: unit test and HIL  
**Artifact**: fsw/src/executive.cpp, fsw/test/test_executive.cpp, obc/Src/freertos/downlink_task.cpp, tools/ground/payload.py, tools/tests/test_payload.py

The per-cycle bound is a real-time budget rather than a preference: the UART's transmit ring is 256 bytes and telemetry already spends about 80 of it each cycle, so a larger burst would block in `uart_write` waiting for the ring to drain and stall the control loop. The image length sent is the JPEG length found by scanning for the end-of-image marker, not the camera FIFO's reported length - those differ by a few hundred bytes of padding, which would otherwise be transmitted during a contact pass.

**REQ-PAY-006** - The ground shall be able to command a multi-frame survey - a sequence of point, capture and downlink at different bearings - and assemble the result into a single image.
**Type**: Functional
**Status**: in progress - **the sequence flies, the image is not worth having yet (2026-08-04)**. One typed word (`survey 4 60`) flew three legs unattended on battery over the radio: point, capture, downlink with selective repeat, park in STANDBY to unwind the wheel, slew, repeat. That half works, and the sequencer is unit-tested.

What does not work is the part that makes it a panorama. **The bearings land short of the commanded ones** - roughly 0, 9 and 28 degrees against a commanded 0, 20, 40 - because a slew that size runs the wheel out of momentum before it arrives (REQ-ADCS-003). Frames a few degrees apart overlap almost entirely, so the assembled strip is three nearly identical pictures rather than a swept scene. The macro is honest about it at the time (`aim timed out - shooting where it points`), and no output is checked in, because a result that looks like a panorama in a filename and not in the file is worse than none.

**It is a ground macro, not a SURVEY mode**, which is what the roadmap first sketched. A mode is a posture the vehicle holds; a survey is a sequence of postures it already has, so a SURVEY mode would have behaved exactly like POINTING except for who was counting - the case `roadmap.md`'s own design rule warns against. The sequencing lives on the ground where it is visible and abortable, the same reasoning the `shoot` macro settled first.

**Owed**: bearing separation the frames can actually use, which is an actuator problem rather than a sequencing one - more wheel momentum (the flywheel has 8 of 16 weight pockets empty) or less bearing friction. The stitcher is a plain side-by-side join with no feature matching, which is the right shape once the frames are far enough apart to need it.
**Verification**: unit tests for the sequencer; HIL for the assembled result, once the slews land
**Artifact**: tools/ground/session.py, tools/tests/test_session.py, tools/stitch.py

**REQ-PAY-005** - The reported size of a captured image shall be the size of the image data, determined by locating its end-of-image marker, and not the raw fill level of the camera's buffer.  
**Type**: Functional  
**Status**: bench-verified (two captures of different scenes both reported a 7688-byte FIFO while their images measured 7265 and 7362 bytes)  
**Verification**: unit test and HIL  
**Artifact**: obc/Src/devices/ov2640.c

## Platform abstraction and portability

**REQ-PAL-001** - The flight software shall reach active platform services - time and outbound link I/O - only through the platform abstraction layer, and shall contain no register or peripheral access. Inbound commands and sensor samples shall enter as cycle inputs assembled at the platform boundary.
**Type**: Constraint  
**Status**: inspection-verified, automated (`tools/tests/test_pal_boundary.py` in `just test`: files under `fsw/src` and `fsw/include` may include only the standard library, `etl/`, `fsw/` and `protocol/`, and may not name a peripheral outside a comment. Its negative cases found a hole in the check itself - the first pattern could not match `NVIC_EnableIRQ`, since `_` is a word character)  
**Verification**: inspection  
**Artifact**: fsw/include/fsw/platform.hpp, fsw/platform/host/platform_host.cpp, tools/tests/test_pal_boundary.py

**REQ-PAL-002** - The identical flight-software source shall build and run on the host (SIL) and cross-compile onto the STM32 (HIL and flight); only the platform backend shall differ.  
**Type**: Constraint  
**Status**: bench-verified (the unmodified flight-software library builds and runs on both targets; the STM32 image beacons its real mode and fault state)  
**Verification**: inspection and build (both targets compile the same sources)  
**Artifact**: backend chosen per executable (host backend for the unit tests, SIL backend in fsw/sil/sil_shim.cpp, STM32 backend in fsw/platform/stm32/platform_stm32.cpp); docs/reports/hil/HIL-001.md

## Verification and traceability

**REQ-VV-001** - The SIL harness shall drive the flight software from a declared scenario - an initial state, an input and fault timeline, and the expected response - and shall emit a pass/fail report. The runner shall be scenario-agnostic: any scenario it can express runs the same way, with no fault-specific logic in the runner.  
**Type**: Functional  
**Status**: SIL-verified (two scenarios of different kinds run through the unmodified runner)  
**Verification**: demonstration (a scenario produces a report)  
**Artifact**: fsw/sil/sil_shim.cpp, tools/sil_runner.py, docs/reports/sil/SIL-001.md, docs/reports/sil/SIL-002.md

**REQ-VV-002** - Every SIL and HIL scenario shall have an id and shall trace to the requirement(s) it verifies; the report shall record the scenario id, the requirement id, and the observed versus expected result.  
**Type**: Constraint  
**Status**: SIL-verified  
**Verification**: inspection  
**Artifact**: fsw/sil/scenarios/, fsw/hil/scenarios/, docs/reports/, docs/verification.md

**REQ-VV-003** - The HIL harness shall consume live STM32 telemetry, detect link loss against a heartbeat timeout, and capture packet timing.  
**Type**: Functional  
**Status**: HIL-verified (loss declared 5.03 s after the last live heartbeat and recovery observed; packet timing measured on the scope)  
**Verification**: HIL (timing capture + timeout demonstration)  
**Artifact**: tools/hil_runner.py, docs/reports/hil/HIL-001.md, docs/reports/hil/HIL-002.md, docs/reports/hil/HIL-001-scope.md

**REQ-VV-004** - Every requirement shall trace forward to at least one verifying artifact, and code and tests shall trace back to a requirement id; the trace shall be kept current as the system evolves.  
**Type**: Constraint  
**Status**: unit-verified (checked automatically both ways on every test run, so the trace cannot rot silently between reviews)  
**Verification**: automated check  
**Artifact**: tools/traceability.py, tools/tests/test_traceability.py, plus the REQ ids carried in code, tests, and the transition log

The check runs in two directions because they catch different decay. Forward: a requirement whose status claims verification must name an artifact, and every path it names must exist - this catches evidence deleted, moved, or renamed out from under a claim. Backward: every REQ id cited anywhere in the tree must exist in this document - this catches typos and ids left behind when a requirement is renumbered or dropped. Artifacts that are prose rather than a file are reported as unchecked rather than passed, so the report states what it could not verify instead of implying it did.

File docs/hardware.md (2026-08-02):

# Hardware & mechanical build

The physical "satellite" - a representative (not flight) CubeSat-style structure that holds the avionics, run on the bench. This file covers the physical objects and the mechanical constraints on them: what a part demands of its neighbours, where everything goes on the stack, and what gets printed. The parts themselves are listed in [bom.md](bom.md); the buses each one sits on, the stack architecture, and the reasoning behind the choices are in [architecture.md](architecture.md); what wire lands where is in [wiring.md](wiring.md).

---

## Part constraints

Standing facts about the parts themselves, as opposed to things that went wrong once - those are in journal.md, dated and with the symptom that found them.

- The **nRF24L01+PA+LNA** needs a 10 uF cap (10-47 uF) across VCC/GND at the module. The PA pulls ~115 mA in bursts and browns out without it. Power it from 3.3 V, not 5 V - its logic inputs are 5 V tolerant, VCC is not.
- **No radio transmits without an antenna attached.** TX into an open ANT can damage the power amp.
- The **WS2812 beads are 3.5-5.3 V parts**, so they run off +5V (CN7-18) with 3.3 V data straight in. A 3.3 V supply is under minimum and they never light, however clean the data.
- **The WS2812 pigtail silkscreen is a trap:** "DO" reads as "D0" and "DI" as "D1" at that size, which inverts the meaning. Establish data direction by continuity from the LED chip's own pins to the pigtail wires, not from the printing. Getting it backwards is harmless - nothing lights, nothing is damaged - and the fix is to feed the other end of the chain.
- The **AS5600 needs a diametrically magnetized magnet** centred on the rotor - an axial disc will not work - and its DIR pin tied to GND at the board. Floating DIR gives undefined rotation direction.
- **USART2 (PA2/PA3) is the ST-Link VCP** and is isolated from the header pins by default (UM1724 solder bridges). Anything that needs probing on a header goes on USART6.
- The **INA228 reads ~18% higher current than the bench PSU's display** (200 mA against 170 mA; power tracks it). Voltage agrees to 0.4% and the INA's own V x I = P is self-consistent, so the discrepancy is the current channel alone - most likely the PSU's ammeter, since 170 mA is 3.4% of its 5 A full scale while the INA228 is a 20-bit part good to ~0.5%. Not worth fixing: thresholds are sized from observed readings, so a systematic offset cancels. Arbitrate with a handheld meter in series before trusting `SHUNT_CAL` for energy accounting.

## Tools

Owned bench kit: Siglent SDS804X HD scope, USB logic analyzer, multimeter, adjustable bench PSU, JST-SH crimp kit. What each is for, when it shows up, and what to practice on it:

### Bench instruments

- **Oscilloscope - Siglent SDS804X HD.** 4-channel, 12-bit. The main analog-signal and timing tool. *First use (Phase 1, done):* probed the LED GPIO (PA5) and measured the blink, then probed the telemetry **downlink TX** and used **UART serial decode** to read a heartbeat frame off the wire (115200 8N1), byte-for-byte matching the host decode. Gotcha learned: USART2 is not on the headers (it is the ST-Link VCP, isolated by default), so the scope-able line is **USART6/PC6** - exactly why the downlink UART exists. *Phase 4:* packet period/jitter, signal integrity. *Phase 5:* I2C/SPI waveforms and decode. *Phase 6:* the watchdog reset pulse. *Phase 7:* FOC driver PWM and motor phases. *Learn:* probe compensation, edge triggering, timebase and volts/div, serial decode, measurements.
- **Logic analyzer.** Cheap multi-channel USB digital capture. Complements the scope when several digital lines need decoding at once (bus plus chip-selects).
- **Multimeter.** Continuity, rail voltages, basic current. Always the first sanity check before powering or probing anything.

### Software toolchain

- **STM32CubeIDE.** Eclipse-based, so a clunky editor, but the debugger works out of the box. Its debugger **is `arm-none-eabi-gdb`**, so using it teaches GDB. The flashable image comes from the CMake cross-build (`just obc-build`), not from the IDE - see [setup.md](setup.md).
- **GDB / SWD.** In CubeIDE: breakpoints, step, watch, registers, memory, peripheral view - this *is* GDB. For the raw-CLI experience, drive `arm-none-eabi-gdb` against OpenOCD or the ST-Link GDB server (`target remote :3333`, `monitor reset halt`, `load`, `break main`). SWD is the 2-wire debug transport (SWDIO/SWCLK). Host side: a MinGW gdb debugs the `fsw` doctest binary on the PC, same commands, so it doubles as practice for the target.
- **git + SSH signing.** Run git from Windows (PowerShell 7), not WSL. Commits are SSH-signed and show Verified; Conventional Commits, every commit explicitly authored by Keating.
- **pre-commit + clang-format + ruff.** Auto-format/lint on commit; `just format` runs it on everything, `just hooks` installs it. CI runs the same checks. A failed hook edits the file and aborts - re-stage and commit again.
- **clang-tidy.** Parses like a compiler and flags real bugs (null derefs, unnecessary copies, missing `override`, narrowing) beyond clang-format's pure style. Runs as a CI gate on `fsw`. Not a GCC replacement - it only analyzes, and it lives in CI on Linux where clang finds the headers.
- **ETL (Embedded Template Library).** Fixed-capacity, no-heap STL-like containers, vendored at `vendor/etl`. Reach for an ETL container wherever a heap-using STL container would otherwise go on the target. Currently backs the mode-transition log.
- **Fusion 360.** The printed frame, mounts, and reaction-wheel parts - see the CAD section below.

## Placement rules

Where every object goes, how it must be oriented, and how close it can sit to its neighbours. Lay parts out physically against these before committing to a model. Each item lists the hard conditions and the reason, so when two rules fight you know which to bend.

### Coordinate frame

- **Z** is vertical = the pivot axis = the lazy-susan centre = the motor spin axis. The platform rotates about Z.
- **X-Y** is the platform plane. Take +X as the camera-facing direction so "front" is unambiguous; origin on the pivot axis.

### Global rules

- **Everything fits inside a ~100 mm cube**, antennas included. The lazy-susan is the only thing allowed to overhang, below the bottom plate.
- **Mass balance is the master rule.** The whole rotating assembly's centre of gravity must sit on the Z pivot axis. Off-axis CG puts a standing gravity torque on the platform that the reaction wheel has to fight, and the pointing demo will not work. Place heavy items symmetrically or counterweight opposite. Test it: a balanced platform, nudged, does not always drift back to the same heading.
- **Keep the CG low** where you have the choice, but **on-axis beats low** if they conflict.
- **Boards mount on standoffs, never flush** - air gap, no shorts, no flex.
- **Locking/crimped connectors only** on the spinning rig.
- **Single-point (star) ground** at the supply negative; the OBC<->ESC link needs the shared reference.
- **Three things repel their neighbours:** magnetic fields (motor + encoder magnet) push the IMU away; RF antennas need clear air; heat (ESC, motor, bucks) stays away from the battery.
- **Route the harness clear of the flywheel and rotor** - nothing in the swept volume, and nothing able to flop into it.

**Priority when conditions conflict:** (1) motor + flywheel + encoder coaxial on Z, (2) mass balance, (3) IMU away from magnets and high-current wires, (4) antenna clearance, (5) heat separation, (6) access/convenience.

### Reaction-wheel core

- **Motor (GBM4108-120T):** spin axis exactly on the Z pivot axis, coaxial with the lazy-susan centre within ~0.5 mm and with no tilt - wheel torque has to act about the same axis the platform turns on. Vertical, stator rigidly bolted to the gimbal plate through its bracket, rotor/bell on the flywheel side. Its permanent magnets are the IMU's worst enemy.
- **Flywheel:** coaxial with the motor and the pivot axis, flat, concentric within ~0.25 mm - an off-centre or tilted wheel wobbles and wrecks the balance. Balanced in itself (trim until there is no heavy spot). **Clear swept volume:** a full cylinder around it plus a few mm, with nothing in it. Rim-weighted for inertia, rim kept symmetric.
  - **Sizing it: the platform turns only when wheel torque (tau = I x alpha) clears the bearing's breakaway friction**, so there are two levers, not one. On inertia: **I is proportional to m x r^2**, so radius counts quadratically and mass only linearly - fill every weight pocket **outermost first** (mass near the hub contributes almost nothing), and expanding the radius even 10% buys 1.21x the inertia for the same mass. Keep the mass symmetric: an unbalanced wheel vibrates *and* pushes the CG off-axis, which raises bearing friction and works against you. Weights must be **captive** - a bolt leaving a spinning wheel is a hazard.
  - **Material does not matter for inertia.** The steel weights are the mass; PETG (~1.27) versus PLA (~1.24) is a rounding error and both are ~6x less dense than the bolts. PLA is if anything preferable here - stiffer, so the rim holds shape and retains the weights. Print generous walls around the pockets.
  - **The friction lever is usually the bigger win.** Degrease the lazy-susan and re-lube light: factory grease is thick and dominates stiction. Keep the stack light and the CG centred, since friction scales with normal force and an off-centre load binds the race.
  - **Reaction torque only exists while the wheel's speed is *changing*** (tau = I x alpha). At constant flywheel speed the platform feels nothing but bearing drag, so a steadily-spinning wheel will never rotate the platform continuously - the demo is a **transient**. Step the wheel T0 -> T8 and watch the platform kick one way, T8 -> T0 and it kicks back; oscillating between two speeds makes it rock visibly. Put a marker on the platform edge so a few degrees is legible. (This is also why real spacecraft need momentum dumping: the wheel saturates and magnetorquers shed the accumulated momentum.)
  - **Tether routing dominates a bench test.** Bring the USB and supply leads **up along the spin axis**, never out radially: an axial wire only has to twist, which costs almost no torque, while a radial one has to drag and bend and will mask the effect entirely.
  - **Measure before optimising:** hang a known weight on a string at a known radius and find the force that just starts it turning - breakaway torque = force x radius - then compare against the wheel's achievable I x alpha. That tells you whether you need 20% more inertia or 3x, i.e. whether pocket-filling suffices or the bifilar-suspension fallback is needed.
- **AS5600 + diametric magnet:** magnet on the rotor shaft end, centred on the spin axis within ~0.25-0.5 mm, turning with the rotor, and **diametrically magnetised** - a standard axial disc magnet will not work. The IC fixes to the stator side, centred on the spin axis, facing the magnet across a **0.5-3 mm air gap (aim 1-2 mm)**, sense centre coaxial within ~0.25 mm. Nothing magnetic or ferrous near it but its own magnet. It wires to the ESC, short run.
- **ESC (B-G431B-ESC1):** near the motor so the three phase wires stay short. Give it air - it runs warm. Noise source: keep it and its phase wires away from the IMU, the INA228 sense, and the antennas.
- **Lazy-susan bearing:** under the bottom plate, its axis = Z, centred, platform sitting level. It may be wider than the 100 mm body since it lives below it. Test its stiction by hand early - the #1 mechanical risk. **The fallback if it is too stiff for clean pointing** is a torsion / bifilar suspension: hang the platform from a thin wire so it rotates near-frictionless, which is the standard cheap reaction-wheel-demo pivot. The wire's slight restoring torque is fine for detumble and pointing, and it kills stick-slip entirely.

### Sensors

- **ICM-20948 IMU (the fussy one):** rigid to the plate - it reports the platform's attitude, so no flex or rattle, axes square to the body frame (note the mounted orientation so firmware can remap). **Far from every magnet and high-current wire**: the motor magnets, the AS5600 magnet, the phase wires, and the battery leads all corrupt the magnetometer, and the mag is what corrects gyro drift. Aim for 30-50 mm+ from the motor/magnet and never route motor or battery current past it. Also keep it clear of the ESC and bucks.
- **INA228:** in the power path - its shunt sits inline with the rail it watches, so it goes where the measured current flows. STEMMA QT daisy-chains on to the TMP117, so keep the two within cable reach.
- **TMP117:** placeable - put it where the temperature you care about is (structure for ambient, or near the ESC/motor to watch their heat). Good thermal contact with whatever it measures.
- **ArduCAM (OV2640):** at a frame opening, lens pointing out, **clear unobstructed field of view** - nothing in the cone. Sensor perpendicular to the view; note which way is "up" in the image. Leave room for the lens to screw in and out for focus.

### Comms

- **RFM95 LoRa:** near an edge/top with the antenna in clear air, running as straight as possible, away from metal (flywheel, battery) and from the other antenna. Fed from the dedicated 3.3 V buck, not the Nucleo 3V3.
- **nRF24L01+PA+LNA:** same antenna-clearance story for its 2.4 GHz whip - the hardest thing to fit inside 100 mm, so plan its space first. **10 uF right at the module's VCC/GND.** 3.3 V from the radio buck.
- **Antennas generally:** clear of metal and of each other; separate the 915 MHz and 2.4 GHz elements. SMA dimensions are standardized, so an antenna mount can be modeled before the part is in hand. The printed frame is plastic (good); the flywheel and battery are not. **Never transmit without an antenna attached.**

### Power and misc

- **Battery (Phase 8):** the heaviest item, so it dominates the balance - place it to bring the rotating CG onto the axis, low if you can. Firmly secured against vibration. Away from ESC/motor heat, accessible to swap and charge, XT60 reachable. Its high-current leads stay away from the IMU and the antennas.
- **Buck converters:** near the power input (short high-current input runs). They get warm and they switch - give them air and keep them away from the IMU, the INA228 sense, and the antennas.
- **WS2812 status LEDs:** visible from outside - the array shows mode/fault/link, so it faces up from the top module's centre, readable at any spin angle.
- **Harness:** locking/crimped connectors, everything routed clear of the flywheel, service loops and strain relief. Motor phase wires and battery leads short, bundled, and away from the IMU and antennas.

### Keep-away matrix

| This... | must stay away from... | because |
| --- | --- | --- |
| IMU (magnetometer) | motor magnets, AS5600 magnet, motor/battery wires, bucks | corrupts the mag heading |
| LoRa antenna | nRF24 antenna, flywheel, battery | detuning / coupling |
| nRF24 antenna | LoRa antenna, metal | detuning |
| Flywheel swept volume | everything | collision |
| Battery | ESC/motor heat | LiPo safety + drift |
| ESC / bucks (noise + heat) | IMU, INA228 sense, antennas, battery | noise + heat |

## The ground station

A separate box on the desk, not part of the spacecraft. One **Feather M0 RFM95**, which is both the LoRa radio and the host - it leaves SPI free for a second **nRF24** and I2C free for an **SSD1306 OLED**, and it is its own USB serial port, so there is no separate host board. (A Teensy was the plan until 2026-07-30.) Connections are in [wiring.md](wiring.md).

**Its LoRa antenna is a soldered wire, not a connector.** The Feather M0 RFM95 (#3178) ships with no antenna connector and the board on the bench has no usable uFL or edge-SMA footprint, so the antenna is a quarter-wave wire soldered into the ANT through-hole: **8.2 cm at 915 MHz** (c/f/4; insulated wire runs a few percent short, so 7.8-8.2 cm is the window). Solder it before the first transmit - this is the one board here whose antenna is something to remember rather than something already attached.

The two ends of the link deliberately do not match. A link needs each end resonant at 915 MHz and properly fed, not identical hardware: the satellite keeps its right-angle SMA stub because it has to lie flat on a spinning plate, and a straight quarter-wave is often the better radiator anyway, since screw-on stubs are helicals compromised for size. If range ever disappoints, the fix is a counterpoise - a second 8.2 cm wire on a GND pad pointing the other way makes it a rough dipole, which helps more than swapping antennas would.

**CAD:** modeled as `ground_assembly` in `cad/` - a `ground_plate` carrying the 4x6 protoboard (Feather + nRF24), a `ground_cover` over it, and the vendor OLED model placed for fit.

## 3D-printed parts and CAD (Fusion 360 -> `cad/`)

Mechanical models live in `cad/` in the main repo. Parts are hand-modeled in Fusion (parametric where it helps); the Fusion cloud project is the editable master, and **STEP is what the repo tracks** - exported per part and per assembly, with a `_vNN` suffix carrying the revision.

**Design around the hard-fit parts.** The motor (bell/shaft/holes) and the bearing (OD/ID/height) are precise physical interfaces - have both in hand, then model the flywheel, motor bracket, platform, and bearing seat to their real dimensions rather than printing first and hunting for a fit.

### Folder layout

```
cad/
  assemblies/     combined models, one per plate of the stack
    comms/              comms_assembly + rf/
    compute/            compute_assembly + power/ + sensor/
    gimbal/             gimbal_assembly + rw/
    satellite_assembly  the whole three-plate stack
    ground_assembly     the ground station box
  printed/        parts designed here and FDM-printed
  lib/            authored building blocks reused across assemblies (the protoboards)
  hardware/       off-the-shelf fasteners (McMaster imports), one file per size
    inserts/  nuts/  screws_bolts/  standoffs/
  reference/      vendor component CAD - placed for fit, never edited - by subsystem
    actuation/      gimbal motor, ESC
    comms/          LoRa, nRF24, SMA edge connector
    compute/        the Nucleo
    ground/         the 0.96" OLED
    power/          battery, buck
    sensors/        AS5600 encoder + its diametric magnet
```

The assemblies mirror the **three-plate stack** (gimbal / compute / comms), with `satellite_assembly` combining them; `ground_assembly` is the box on the desk.

**The one rule that decides where a file goes: did I author it?**

- **Authored** (editable, your IP): `assemblies/`, `printed/`, `lib/`.
- **Off-the-shelf** (placed but never edited): `reference/` (vendor models, grouped by subsystem) and `hardware/` (fasteners). The two stay separate on purpose - a screw is not a reaction wheel.

### Printed parts

| Part | What it is |
| ---- | --- |
| `gimbal_plate` | the bottom plate - motor, flywheel, encoder, lazy-susan |
| `compute_plate` | the middle plate |
| `compute_mount` | the mount carrying the compute-plate electronics |
| `comms_plate` | the top plate - radios, LED array, switch (Phase 8) |
| `flywheel` | the reaction wheel |
| `driver_cover` | cover over the ESC |
| `buck_cover` | cover over the buck converters |
| `led_cover` | diffuser over the status LED array |
| `top_cover` | the stack's top cover |
| `ground_plate` | the ground station's base plate |
| `ground_cover` | the ground station's cover |

### lib - authored building blocks

The protoboards, modeled once and instanced wherever they appear: **4x6** (power and radio boards) and **7x9** (sensor and stm32 boards). Reuse them rather than copying - fix a dimension once and every assembly updates.

### What is deliberately not modeled

`reference/` carries only the components whose dimensions actually drive the design. Several devices - the IMU, INA228, TMP117, and the ArduCAM - are **intentionally absent**: their fit was confirmed physically on the real protoboard, so modeling them would add work without informing a decision. That is a decision, not a gap. Model a vendor part only when a clearance, a hole pattern, or a keep-out depends on it.

### Hardware / fasteners

**One shared folder, not per-assembly.** Screws, nuts, standoffs, and heat-set inserts live in `hardware/`, one file per unique size, inserted as many occurrences as needed. Duplicating a screw into every assembly is the thing to avoid.

Getting them in: **Insert -> McMaster-Carr Component** is built into Fusion - search the exact metric part, pick STEP, and it drops in at real dimensions. Manufacturer STEP or GrabCAD covers anything McMaster does not list.

Length matters for **standoffs** (they set board-to-board spacing, a real dimension the frame depends on) and for **screws** only where one has to clear a board or bottom out in a standoff. Don't model real threads - they are heavy and slow; a cosmetic thread or plain shaft at the nominal diameter is right, since clearance holes care about the clearance diameter.

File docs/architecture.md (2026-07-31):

# Architecture

Flight behavior gets worked out in software before the STM32 has to prove it on the bench. Python drives declared test scenarios into the C++ flight logic, first on the host (SIL) and later against the real STM32 node over UART (HIL).

```text
Python scenario runner  (YAML scenarios: fault injection, grading, pass/fail reports)
        |
        v
C++ flight software     (modes, faults, commands, telemetry)
        |
        +----------------------------+
        v                            v
SIL shim (host exe,           STM32 HIL node
injected time + faults)       (bare-metal UART packets first; sensors and watchdog later)
```

Scenarios in `fsw/sil/scenarios/` drive the unmodified flight-software library through a shim executable; the runner grades what happened and writes reports to `docs/reports/`. Details in [verification.md](verification.md).

For the attitude scenarios the harness also runs a **plant model** (`fsw/sil/plant.cpp`) - a single-axis rigid body with one reaction wheel, written in-repo. It carries the momentum exchange (a wheel torque is felt by the platform equal and opposite), stick-slip and viscous bearing friction, and the wheel's own speed limit, which is what makes saturation a thing a scenario can observe. Its numbers are measured, not assumed: inertias from the Fusion model (j_wheel 1.09e-4, j_platform 4.53e-3 kg m^2) and friction fitted to a hand-timed coast-down. Together those put the wheel's authority at 0.87 rad/s of platform rate - a number worth knowing, because the first guess at it was 3.6.

## Language split

| Area | Language | What it does |
| ---- | --- | --- |
| STM32 firmware | C | CMSIS register-level startup, drivers, interrupts, timers, UART/SPI/I2C, ADC, GPIO, watchdog, low-level packet I/O |
| Flight software | C++ | mode manager, fault manager, sensor monitor, command validation, telemetry model, host unit tests |
| Test and analysis | Python | scenario execution, SIL/HIL orchestration, plotting, log parsing, reports |

The flight logic lives in `fsw/` and is written to be portable. It runs on the host for development and SIL, and the same source cross-compiles onto the STM32 for the integrated build, where it joins the firmware as the on-board computer. It never touches registers directly - it reaches hardware through a platform abstraction layer, backed by the simulator on the host and by the C firmware drivers on the target. The split is by layer, not by folder: the firmware owns the hardware (registers, peripherals, low-level I/O), the flight software owns the decisions (modes, faults, commands), and they meet at that boundary. The flight software allocates nothing dynamically - it uses fixed-capacity containers (ETL) so the same code runs on the host and on the no-heap target.

## Communication links

Everything between the satellite and the ground rides framed, CRC-checked packets (`common/protocol/`), but it is not one undifferentiated "telemetry" stream - there are two logical links with different jobs.

```text
   SATELLITE (OBC)                                   GROUND STATION (feather m0 + host pc)

   TT&C link - telemetry down + commands up, low-rate, always on (UART / LoRa RFM95)
        commands   <---------------------------------   SET_MODE, CLEAR_FAULT, NOOP, ...                (uplink)
        telemetry  --------------------------------->   heartbeat (mode + fault bitmask), link status, acks  (downlink)

   payload link - high-rate, only in DOWNLINK mode (nRF24 2.4 GHz)
        payload    --------------------------------->   bulk imaging data, chunked over a contact pass  (downlink)
```

The **TT&C link** (telemetry, tracking & command - the standard name for a spacecraft's low-rate housekeeping channel) carries commands up and housekeeping telemetry down. It is low-rate and stays on so the ground can always reach the spacecraft. The **payload link** is separate and high-rate; it powers up only in DOWNLINK mode to empty the imaging buffer over a contact pass, because a power-hungry high-rate radio cannot be always on. Both carry the same frame format - only the transport changes - so the codec is written once.

Telemetry and downlink are not the same thing. Telemetry is the continuous housekeeping beacon (mode, faults, health) on the TT&C link; "downlink" is the payload-emptying *mode* on the payload link. Both travel satellite-to-ground, but they are different content on different links.

### What the satellite can observe

The spacecraft only ever sees its own end of a link - it cannot hear its own transmissions, so it can never directly know whether the ground received a downlink. That asymmetry sets which link faults exist at all:

- Uplink silence is observable. If no valid command arrives within a timeout, a command-loss timer raises `COMMAND_LINK_LOSS` - the one onboard link-health fault, meaning ground contact is lost, detected purely from the command (uplink) half of the TT&C link going quiet.
- Downlink delivery is not observable onboard. Whether the ground is hearing the telemetry is detected on the ground, from gaps in the heartbeat sequence number - never by a fault on the satellite.
- Sequence numbers (`command_t.seq`, `heartbeat_t.seq`) detect drops, not loss - the receiving end spotting a missed or duplicate packet, a finer signal than the link being down.
- `uart_status_t` reports link quality (UART receive-line error counts: overrun, framing, noise, dropped) as diagnostic telemetry, not as a fault. Each transport gets its own status message as it lands (LoRa: RSSI/SNR, nRF24: retransmit counts), since the quality observables are transport-specific.
- The payload link could be the exception, since the nRF24 can auto-acknowledge - but it is deliberately run with auto-ack off, so the vehicle never stalls a downlink against a ground station that might not be listening. `PAYLOAD_LINK_LOSS` therefore does not exist: turning it on would trade a downlink that always makes progress for a fault nobody responds to.

### Beacon rates and the loss timeout

Both directions beacon at 1 Hz: the satellite sends a heartbeat every second, and the ground sends a NOOP keep-alive every second. That is what NOOP is for - the command-loss timer only works if the ground is expected to keep talking. Either end declares link loss after 5 seconds of silence, enough missed beacons that a few dropped packets do not trip it. These are bench rates, chosen so a person watching the console can see the system breathe; a real spacecraft would beacon slower and tolerate much longer command silence, but the same logic applies with different constants.

## Onboard interfaces

Separate from the comm links above. Those carry the spacecraft-to-ground contract - framed, CRC-checked packets. The onboard interfaces are how the OBC reaches its own sensors on the satellite itself. This traffic never leaves the board and is not framed - each device speaks its own native register protocol, handled in its driver under `obc/`. Selected readings are then repackaged into downlink telemetry (for example `imu_data_t`) and sent to ground over a comm link, but the onboard bus read and the downlink packet are two different things: the read is a register access over SPI or I2C, the packet is a framed message over the link.

| Peripheral | Bus | How the OBC talks to it | Status |
| --- | --- | --- | --- |
| ICM-20948 IMU (accel + gyro, plus the AK09916 magnetometer) | SPI2 | register read/write; the mag is polled through the IMU's own internal I2C master and read back in the same burst | on the bench |
| INA228 power monitor | I2C1 | register reads - bus voltage, current, and power, sensed high-side on the main battery bus | on the bench |
| TMP117 temperature | I2C1 | register reads - placeable structural temperature | on the bench |
| OV2640 camera (ArduCAM) | SPI3 + I2C1 | two buses at once: SCCB register writes over I2C to configure the sensor, SPI to read frames out of the onboard FIFO | on the bench |
| B-G431B-ESC1 reaction-wheel driver | USART1 | framed torque commands out, wheel status back; the ESC closes the FOC loop locally against its own encoder | link proven; ESC out of the rig |
| RFM95 LoRa (915 MHz) | SPI3 | TT&C beacon out, ground commands in; 1 Mbps is not the point, always-on is | on the bench |
| nRF24L01+ (2.4 GHz) | SPI3 | payload chunks out, transmit only, live only in DOWNLINK | on the bench |
| WS2812 status LEDs | GPIO (PA8) | one timed data line, three beads chained - mode, fault, and link | on the bench |

The I2C bus runs at **100 kHz, not 400 kHz**. Once the slice, the harness, and three devices were all on it, the measured 10-90% rise time on SCL landed around 600-1000 ns - inside standard mode's 1000 ns budget but well past fast mode's 300 ns. The bus sits under 2% busy either way, so there was nothing to gain from pushing it.

## Fault handling and sensor monitoring

Fault detection, isolation, and recovery (FDIR) is one pipeline that every fault flows through: detect -> debounce -> latch -> respond. A condition is sampled each control cycle; a fault latches only after a set number of consecutive bad samples (debounce, so a single transient never trips it); once latched it stays latched until it is explicitly cleared; and its response is driven by its severity. The per-fault policy - severity, debounce threshold, owning requirement - lives in one table in the fault manager, so adding a fault is a table row, not new logic. The full catalog and the per-fault requirements are in [requirements.md](requirements.md).

Severity decides the response. A **Warning** is surfaced in telemetry and nothing else - off-nominal but still fully capable. A **Critical** fault forces SAFE if it does not clear. A **Degraded** fault sits between them: a capability was lost but a documented fallback exists, so the spacecraft switches to it and keeps operating rather than safing. The fallbacks are specified in requirements.md - for example, losing the accel/gyro path (`ACCEL_GYRO_DROPOUT`) while pointing or detumbling retreats the spacecraft to STANDBY, since holding attitude without body-rate feedback is unsafe. Losing only the magnetometer (`MAG_DROPOUT`) is a Warning: it is reported, but the spacecraft keeps flying.

Most faults are fed their samples from outside the flight software (the power monitor's voltage, the command-loss timer). Sensor faults are different: the **sensor monitor** is the detect stage for the onboard sensors, turning each cycle's readings into fault samples. It reads the validity flags the drivers attach to every sample - invalid or missing IMU data raises that source's dropout fault, and an invalid INA228 sample raises `POWER_DROPOUT` - and it also watches the values themselves. A live IMU reading always moves a little, so a stream that goes perfectly flat past a staleness window is treated as frozen and raises the same dropout fault. Staleness is a detector for a dropout, not a separate fault. A sensor that simply is not sampled on a given cycle gets no opinion, so a SIL scenario that never exercises a sensor cannot trip its faults. The monitor only detects; the response still happens in the executive's single fault-response step.

Recovery is deliberately conservative and ground-commanded: a latched fault clears only on a CLEAR_FAULT command, never autonomously, so a flapping sensor cannot toggle a fault on and off. A planned RESET_DEVICE command will let the ground re-initialize a misbehaving peripheral before deciding to clear its fault - both routed through the platform abstraction layer as actions the flight software performs, not inputs it reads.

## Firmware approach

Bare metal first: CMSIS startup, clock, a GPIO heartbeat, a SysTick or timer time base, interrupt-driven UART, then simple packet framing. FreeRTOS comes in when the workload turns genuinely concurrent - multiple rate-critical tasks (sensors, telemetry, commands, a control loop) - not before, when a super-loop is enough, and not as an afterthought.

That point arrived once the OBC was sampling four sensors, answering ground commands, and streaming a payload image over one link, all inside a single 10 Hz super-loop where any one blocking read delayed the rest. The task model keeps the concurrency at the platform boundary: **one control task** owns the flight software and calls `Executive::cycle()` exactly as the super-loop did, and every other job runs as its own task that hands work to it through a queue. That is deliberate rather than incidental - the executive being a pure function of its inputs is what lets the host unit tests and the SIL scenarios exercise the same code the target runs, and putting flight state behind mutexes instead would mean the host was testing a different concurrency model than the spacecraft. Mutexes are not ruled out; they guard shared *resources*, not shared decisions. The first one arrived with the second task that writes the console: the UART's transmit ring has one producer per writer task, and `uart_write` holds that lock for the whole of one write so two tasks cannot interleave their bytes into one unreadable frame. The control task runs at the highest priority, the kernel is configured for static allocation only (a dynamically created task or queue fails to link), and the SysTick driver keeps its vector and forwards each tick to the scheduler, so the millisecond time base every log entry is stamped with does not restart when the scheduler does.

The firmware is grouped by layer under `obc/`: `drivers/` (clock, gpio, systick, uart, spi, i2c) - register-level code for the MCU's own peripherals that moves raw bytes - and `devices/` (the ICM-20948 IMU, with the power and temperature sensors as they come up) - the external chips that ride those buses. The frame envelope and message definitions live in `common/protocol/` (C++) - the wire contract the flight software owns and the ground-station firmware will share when it lands. The protocol is the OBC's ground interface, not something the firmware interprets, so the flight software builds and parses the frames while the drivers just carry the bytes. A SysTick time base provides the millisecond clock, and an interrupt-driven multi-instance USART driver spans three UARTs - a console on USART2 (the ST-Link virtual COM port, for the host decoder and debug), a downlink on USART6 (a header pin, so it can be probed on a scope or logic analyzer and later swapped for a radio), and the ESC command link on USART1. The I2C driver is a polled master; bringing the INA228 up on the bench surfaced a documented F4 erratum - the cell leaves its STOP bit wedged after a transfer (es0298 2.11.3) - so each transfer clears that stale stop with a controller reset before it issues a START.

## Nodes

The OBC is not the only processor in the system, so each node that runs its own firmware gets its own top-level directory alongside `obc/` and `fsw/`.

| Path | Node | Runs on |
| ---- | ---- | --- |
| `obc/` + `fsw/` | on-board computer - drivers, flight software | STM32F446 (Nucleo) |
| `esc/` | reaction-wheel driver - FOC, encoder, torque commands | STM32G431 (B-G431B-ESC1) |
| `gsw/` | ground station - receives both links, uplinks commands, drives the readout | Feather M0 RFM95 (SAMD21) |

Each node owns its build and toolchain: the OBC builds with CMake and the `arm-none-eabi` toolchain, which is both the image that gets flashed and the check CI runs, with STM32CubeIDE kept as a debugger rather than a second build; the ESC node is an Arduino sketch on top of SimpleFOC, which handles the current control loop and the AS5600 encoder locally. The OBC only sends it torque targets over UART, so the fast inner loop stays off the flight computer. What crosses between nodes is the wire contract in `common/protocol/`, which the ground-station firmware compiles rather than reimplements - three consumers, one definition.

## Vendored dependencies

Third-party code lives under `vendor/`, never copied into the node trees. Two forms, by one rule: **libraries the build compiles against are submodules; constant data transcribed out of a library is a checked-in file with its provenance recorded.**

The distinction is about what upstream is for. A submodule pins a whole project at a commit and is worth the weight when the project is the thing being used. The OV2640 tables are four constant arrays lifted out of a 115 MB Arduino repository that is otherwise unused here - a submodule would carry the entire library, and its release cadence, to get 19 KB of register values that have not changed in years. Checked in, the file is still byte-exact and still diffable against upstream; `docs/setup.md` has the one-line refetch.

| Path | Form | What it is |
| ---- | ---- | --- |
| `vendor/cmsis-core` | submodule | CMSIS core headers and support |
| `vendor/cmsis-device-f4` | submodule | STM32F4 device headers and startup references |
| `vendor/FreeRTOS-Kernel` | submodule | the RTOS kernel - `tasks.c`, `queue.c`, `list.c`, and the GCC ARM_CM4F port are in the OBC image; nothing else is |
| `vendor/etl` | submodule | the Embedded Template Library - fixed-capacity, no-heap containers for the flight software |
| `vendor/arducam` | checked in | OmniVision's OV2640 register tables by way of ArduCAM's library, plus the small shim that lets them compile outside Arduino |

Everything under `vendor/` is excluded from the formatters, so vendored files stay byte-identical to upstream.

## Stack architecture

Three plates on corner standoffs, stacked and spinning as one on the lazy-susan bearing below. Sides are open and wires run straight up through pass-through holes. This replaced an earlier four-wall cube around a central battery: in the actual build the electronics consolidated onto a single middle plate rather than four separate walls.

| Plate | Carries |
| ----- | --- |
| gimbal (bottom) | the GBM4108-120T motor with the flywheel on it, the AS5600 on the shaft end below, and the lazy-susan under the plate - all coaxial with the Z pivot axis |
| compute (middle) | the Nucleo, the ESC, the sensor protoboard (IMU, TMP117, INA228, camera), and the power distribution with the star ground |
| comms (top) | both radios on their own protoboard, the antennas along the top edges, and the status LEDs in the centre where they read at any spin angle |

The battery is the one placement still open - it is not in the build (the bench PSU stands in) and it is the heaviest item, so where it goes decides whether the rotating CG lands on the Z axis. A central column through the plates or a low mount with a counterweight; settle it when the untethered build starts.

Pin assignments and connectors are in [wiring.md](wiring.md); tolerances and keep-aways in [hardware.md](hardware.md).

**EMI is what consolidating cost.** The four-wall plan put the sensors opposite the ESC, because the ESC's phase switching is the worst noise source on the rig and the IMU's magnetometer the most sensitive part. One middle plate puts them together, and the IMU now sits above the motor's magnets as well - so the separation has to be won back by layout: IMU at the far corner with the ESC and its phase wires clustered opposite, as much vertical gap and lateral offset from the motor as the plate allows, and motor and battery leads routed hugging the ESC side, never past the IMU or the INA228 sense.

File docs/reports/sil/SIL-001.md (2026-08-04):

# SIL-001 - undervoltage drives safe mode

**Verdict: PASS**

- Scenario: `fsw/sil/scenarios/sil_001_undervoltage.yaml`
- Verifies: REQ-FAULT-002
- Checks: 4/4 passed

## Checks

| Check | Expected | Observed | Result |
| ----- | --- | --- | --- |
| mode_log[0] | `{'to': 'SAFE', 'trigger': 'FaultEntry', 'req': 'REQ-FAULT-002'}` | `{'t': '1600', 'from': 'STANDBY', 'to': 'SAFE', 'trigger': 'FaultEntry', 'req': 'REQ-FAULT-002'}` | pass |
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

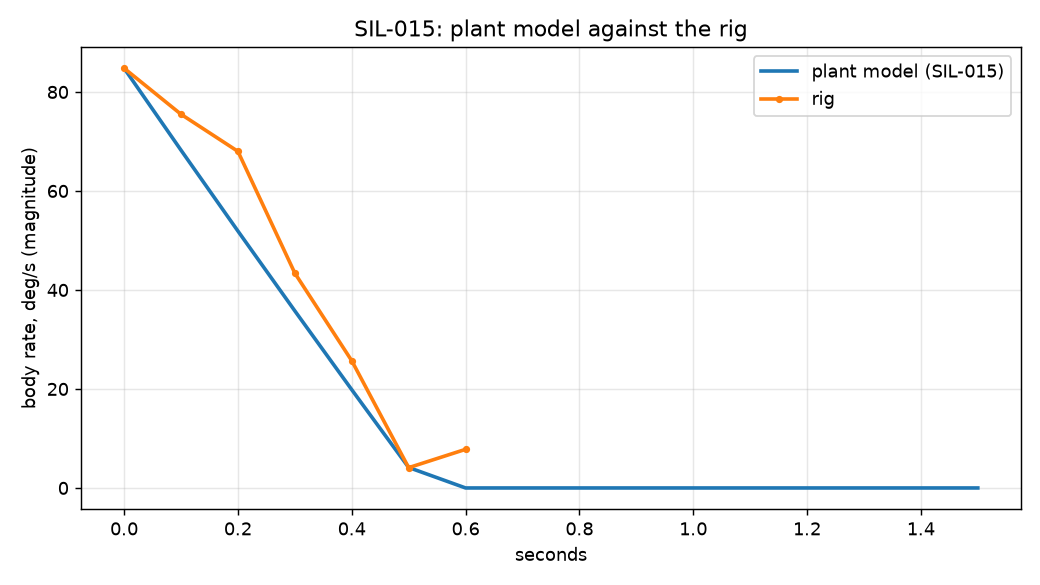
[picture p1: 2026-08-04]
docs/reports/overlay_coast.png

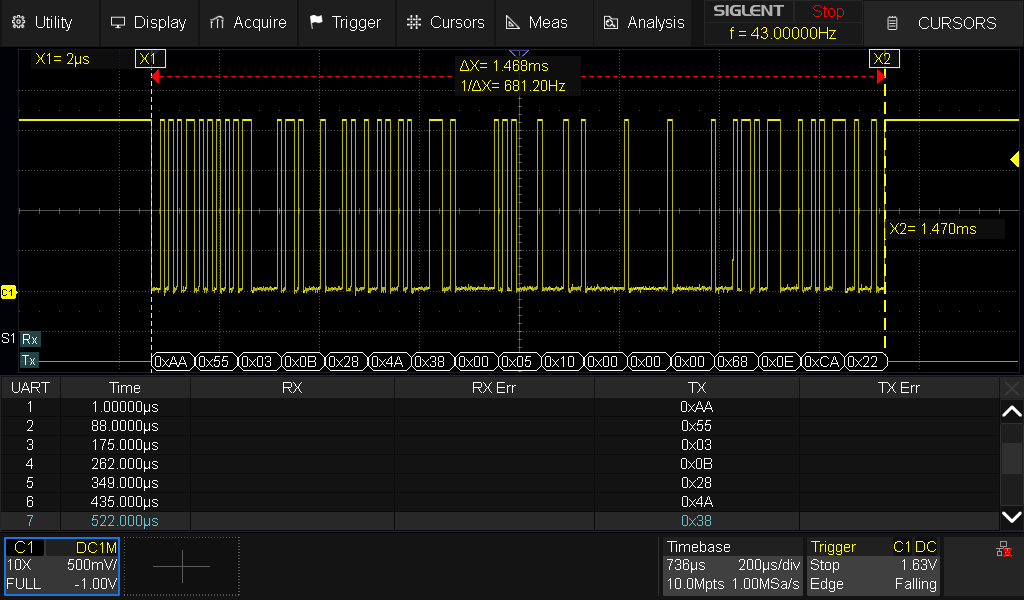
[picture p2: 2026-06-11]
docs/reports/hil/img/HIL-001-frame.png

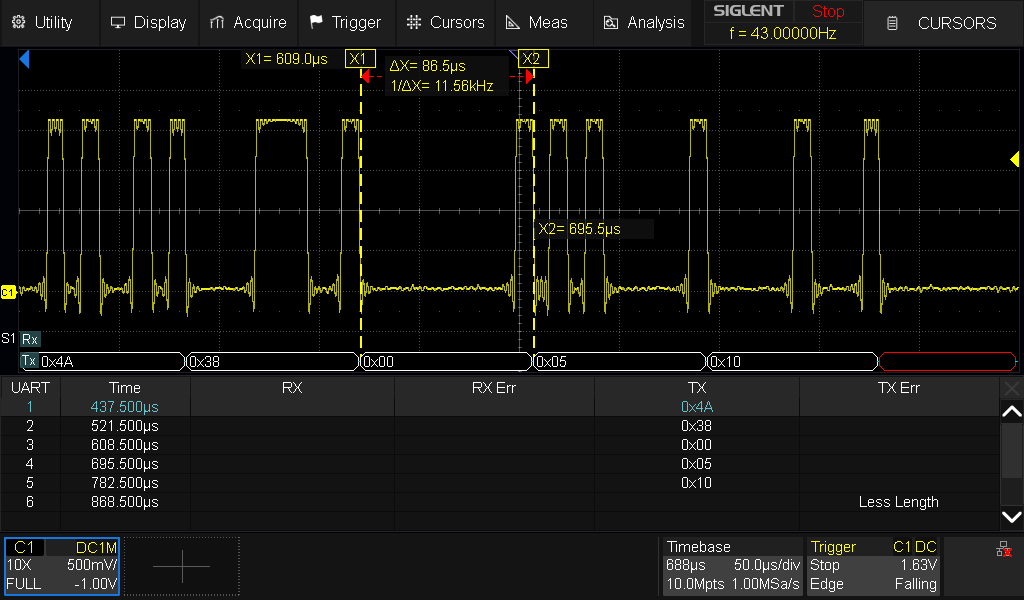
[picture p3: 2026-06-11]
docs/reports/hil/img/HIL-001-interbyte.png

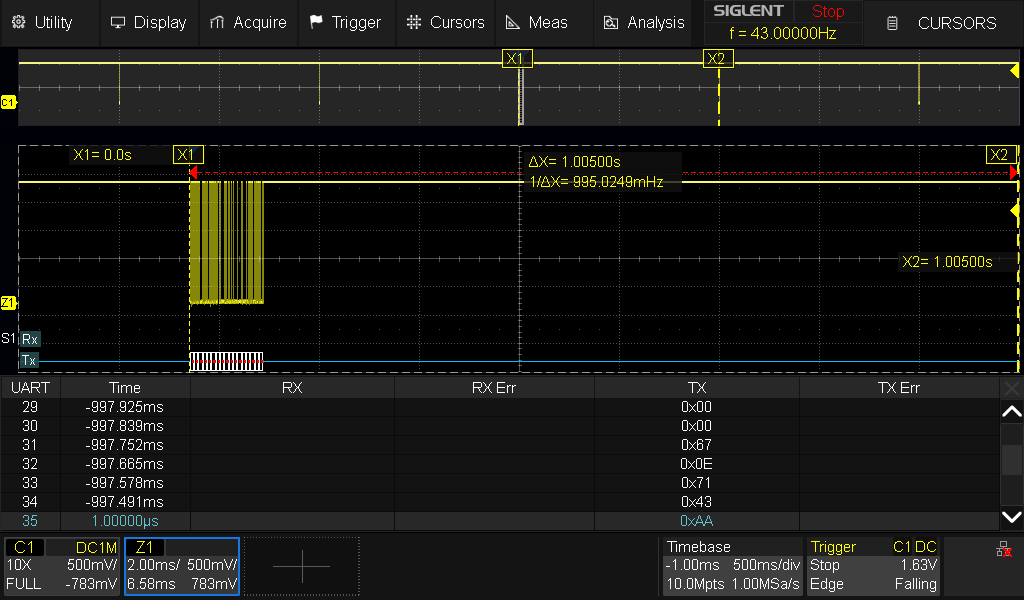
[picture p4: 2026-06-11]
docs/reports/hil/img/HIL-001-period.png

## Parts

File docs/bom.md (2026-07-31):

# Bill of materials

Bench hardware that is actually in use. More sensors and actuator parts get added as they come up.

| Item | Qty | Est. cost | Notes |
| ---- | --- | --- | ----- |
| STM32 Nucleo-F446RE dev board | 1 | $19.00 | The flight computer; onboard ST-Link and USB virtual COM port. |
| Mini-USB cable, data capable | 1 | $8.99 | ST-Link programming and UART-over-USB. |
| Breadboard | 1 | ~$5.00 | Bench wiring. |
| Jumper wires | 1 set | ~$6.00 | Bench wiring. |
| SparkFun ICM-20948 9-DoF IMU breakout | 1 | ~$17.00 | Accel/gyro over SPI, plus the AK09916 magnetometer through the chip's internal I2C master; all three streams are live on the bench. |
| Adafruit INA228 power monitor breakout (#5832) | 1 | $14.95 | Bus voltage/current/power over I2C (20-bit, 85 V); up on the bench, current verified. |
| Adafruit TMP117 temperature breakout (#4821) | 1 | $11.50 | High-accuracy structural temperature over I2C (16-bit, +-0.1 degC, addr 0x48); on the bench reading ~24 degC. |
| ArduCAM Mini 2MP (OV2640) | 1 | $25.99 | Imaging payload, on two buses: SPI3 for the frame FIFO and I2C1 for register config over SCCB. Both answer on the bench - the chip ID reads back and the SPI test register round-trips. The driver is written (ArduChip FIFO control, non-blocking capture, chunked read-out) but has not been run against the camera yet, and the sensor's JPEG register tables still need vendoring. |
| GBM4108-120T gimbal motor | 1 | ~$40.00 | The reaction-wheel actuator. 24N22P, so 11 pole pairs, 12.4 ohm windings. Runs closed-loop FOC on the bench at ~344 RPM for 0.18 A. |
| B-G431B-ESC1 FOC driver | 1 | $19.42 | Runs SimpleFOC and closes the motor loop locally, reading the encoder itself; takes speed/torque commands from the OBC over UART. |
| AS5600 magnetic encoder + diametric magnet | 1 | ~$10.00 | Rotor position for sensored FOC. Wired to the ESC, not the OBC. Verified at 0x36 with the magnet detected, and one hand revolution reads 6.26 rad against 6.28 theoretical. |
| 4in ball-bearing lazy-susan turntable | 1 | ~$12.00 | The pivot the platform spins on - the wheel's torque only shows if the platform turns nearly friction-free. |
| RFM95W 900 MHz LoRa breakout (Adafruit #3072) | 1 | $19.95 | The low-rate TT&C link, satellite side. Wired onto the shared SPI3 bus with its own CS/DIO0/RST; no driver yet. |
| nRF24L01+PA+LNA 2.4 GHz transceiver | 2 | ~$8.50 | The high-rate payload downlink. They come in pairs, so one is the satellite side on SPI3 with its own CSN/CE/IRQ, and the other is the ground station's receiver. Wants a 10 uF cap right at its VCC or the link browns out. |
| 915 MHz right-angle SMA antenna | 1 | ~$4.00 | Screws onto the edge-launch SMA on the LoRa board; the right angle lets it lie flat on the top plate. |
| 2.4 GHz SMA stub antenna | 1 | ~$3.50 | For the nRF24, which arrived bare. |
| MP1584EN buck converter | 2 | ~$2.00 each | 14.8 V down to 5 V for the Nucleo's E5V pin, and to 3.3 V for the radios. Both adjustable, so both need setting with a meter before anything is connected to them. |
| WS2812 RGB LED bead | 3 | (from the Cyberbrick kit) | Status array on the top plate - mode, fault, and link - chained on one data line off PA8. |
| 470 uF / 50 V electrolytic | 1 | ~$0.70 | Bulk cap across the ESC's power input, soaking motor-PWM switching and regen transients. |
| Ovonic 4S 14.8 V 1550 mAh LiPo | 2 | ~$25.00 each | For running untethered. Not in the loop yet - the bench supply stands in until the fuse is fitted. |
| JST-XH connector kit + ratcheting crimper | 1 | ~$25.00 | Every removable connection in the build. XH latches and seats in 0.1in protoboard; JST-PH does neither, which is why it got dropped partway through. |
| XT60 connectors | 3 pairs | ~$8.00 | The battery and the ESC feed - anything carrying motor current. |
| Protoboard, 0.1in double-sided | assorted | ~$10.00 | The OBC slice, sensor board, power distribution board, LED array, and radio module. |

| Adafruit Feather M0 RFM95 (900 MHz) | 1 | ~$34.95 | The ground station. Chosen over a separate Teensy because the LoRa radio is already on the board, SPI stays free for the nRF24 receiver, I2C is free for the display, and it is its own USB serial port - a Teensy would have meant wiring a second RFM95 to gain nothing. |
| SSD1306 0.96in 128x64 I2C OLED | 1 | ~$6.00 | The ground station's local readout. Picked over an I2C 16x2 LCD for two reasons: those LCD backpacks are 5 V parts whose I2C pull-ups would put 5 V on the Feather's 3.3 V pins, and 128x64 shows mode, faults, link and sequence at once where 2x16 characters cannot. |

The PTC fuse gets added as it actually goes into the build.

## Datasheets and references

Datasheets are vendored in `docs/datasheets/` and linked by relative path, so they keep opening even when vendor pages move around. Files are grouped by subsystem - `compute/`, `sensors/`, `actuation/`, `payload/`, `comms/`, `power/` - and named `<part-or-doc-id>-<type>.pdf`. New devices get their own block here as they are added.

### STM32 Nucleo-F446RE (STM32F446RE)

- [STM32F446RE datasheet](datasheets/compute/stm32f446re-datasheet.pdf) - pinout, alternate-function mappings, electrical specs
- [RM0390 reference manual](datasheets/compute/rm0390-reference-manual.pdf) - register-level detail for every peripheral
- [PM0214 programming manual](datasheets/compute/pm0214-programming-manual.pdf) - Cortex-M4 core: NVIC, SysTick, SCB, instruction set
- [UM1724 user manual](datasheets/compute/um1724-nucleo64-user-manual.pdf) - the Nucleo-64 board: jumpers, ST-Link, pin mapping
- [ES0298 errata](datasheets/compute/es0298-errata.pdf) - silicon limitations and workarounds
- [Board product page (st.com)](https://www.st.com/en/evaluation-tools/nucleo-f446re.html) - schematics (MB1136) under CAD Resources, plus CubeIDE downloads

### ICM-20948 9-DoF IMU (SparkFun breakout)

- [ICM-20948 datasheet (DS-000189)](datasheets/sensors/icm-20948-datasheet.pdf) - register map (four banks), SPI/I2C interface formats, electrical specs
- [AK09916 datasheet](datasheets/sensors/ak09916-datasheet.pdf) - the magnetometer die inside the package, on its own register map
- [Product page (invensense.tdk.com)](https://invensense.tdk.com/en-us/products/9-axis/icm-20948) - latest datasheet revisions and app notes

The magnetometer needs both sheets open at once. It is a separate chip at 0x0C that the ICM-20948 reaches over its own internal I2C master, so its CNTL2 mode byte and the ST1/ST2 status bytes are in the AK09916 sheet, while the slave-0 registers used to drive it are in the ICM-20948 sheet.

### INA228 power monitor (Adafruit #5832)

- [INA228 datasheet (SLYS021)](datasheets/sensors/ina228-datasheet.pdf) - register map, the SHUNT_CAL / current equations, ADC and conversion config, electrical specs
- [Product page (adafruit.com)](https://www.adafruit.com/product/5832) - the breakout: onboard 15 mohm shunt, STEMMA QT, address jumpers, schematic

### TMP117 temperature sensor (Adafruit #4821)

- [TMP117 datasheet](datasheets/sensors/tmp117-datasheet.pdf) - register map, the temperature result format, config and EEPROM registers, electrical specs
- [Product page (adafruit.com)](https://www.adafruit.com/product/4821) - the breakout: STEMMA QT, the ADDR jumper (default 0x48)

### OV2640 camera (ArduCAM Mini 2MP)

- [OV2640 datasheet](datasheets/payload/ov2640-datasheet.pdf) - sensor register map, the SCCB interface, output formats
- [ArduCAM Mini 2MP hardware application note](datasheets/payload/arducam-m-2mp-hardware-app-note.pdf) - the ArduChip register map on the SPI side: capture control, FIFO clear and burst read, the FIFO length registers
- [ArduCAM Mini 2MP user guide](datasheets/payload/arducam-m-2mp-user-guide.pdf) - board pinout, power, and the capture sequence

The module answers on two buses at once: SCCB (I2C1, 0x30) for register config, and SPI3 for reading frames out of the onboard FIFO. Neither can do the other's job, and the documents split the same way - the OV2640 sheet covers the sensor, the application note covers the ArduChip that buffers it. The OV2640 mode init tables are in neither; those only exist in ArduCAM's library source, as `ov2640_regs.h`.

### B-G431B-ESC1 FOC driver

- [UM2516 user manual](datasheets/actuation/um2516-esc1-user-manual.pdf) - board layout, the J1/J3/J4/J8 connector maps, power stage, and which MCU pins land where
- [Board product page (st.com)](https://www.st.com/en/evaluation-tools/b-g431b-esc1.html) - schematics and CAD under the design resources tab

Two things worth knowing before wiring it: the I2C the encoder needs is the **Hall/encoder pads (J8) repurposed** - PB7 for SDA, PB8 for SCL - and J8's supply line is 5 V, so the AS5600's 3.3 V has to come off the J4 SWD pads instead. The serial console is USART2 on PB3/PB4, not the Arduino default.

### AS5600 magnetic encoder

- [AS5600 datasheet](datasheets/actuation/as5600-datasheet.pdf) - register map, the I2C interface at 0x36, and the status bits

It sits on the ESC's bus, not the OBC's, so there is no driver for it in `obc/` - this sheet is for reading it by hand on the bench or for setting SimpleFOC up. The DIR pin picks which way counts up: tied to ground the value increases clockwise, tied to VDD it increases counterclockwise. Magnet placement shows up in the status register rather than as a bad angle - MD means detected, ML means too weak or too far, MH means too strong or too close.

### RFM95W LoRa radio (Adafruit #3072)

- [SX1276/77/78/79 datasheet](datasheets/comms/sx1276-datasheet.pdf) - the transceiver itself: register map, LoRa modem config, FIFO and DIO mapping
- [RFM95/96/97/98(W) module datasheet](datasheets/comms/rfm95-datasheet.pdf) - the HopeRF module built around it: pinout, RF specs, antenna port
- [SX1276 product page (semtech.com)](https://www.semtech.com/products/wireless-rf/lora-connect/sx1276) - errata and application notes
- [Breakout product page (adafruit.com)](https://www.adafruit.com/product/3072) - the breakout: 3.3 V regulator, level shifting, pin labels

Two sheets because they cover different halves. The driver talks to the SX1276, so that is the one with the registers in it; the HopeRF sheet is for pinout and RF only.

### nRF24L01+ transceiver

- [nRF24L01+ product specification](datasheets/comms/nrf24l01p-datasheet.pdf) - register map, Enhanced ShockBurst, and the auto-acknowledge behavior the payload link leans on
- [nRF24 series page (nordicsemi.com)](https://www.nordicsemi.com/Products/nRF24-series) - the family page and the evaluation kit files

It has to be the **plus** specification. The original nRF24L01 sheet is a different part with the same name on the cover: on the +, RF_SETUP bit 5 selects the 250 kbps rate, where the original reserves that bit and requires it written as zero.

### MP1584EN buck converters

- [MP1584 datasheet](datasheets/power/mp1584-datasheet.pdf) - the regulator on the module: 4.5-28 V in, 3 A, 1.5 MHz switching, and the 0.8 V feedback reference

Both modules are the adjustable kind, so the trim pot has to be set with a meter on the output before anything gets wired to it - whatever they ship at is arbitrary. The 14.8 V bus sits comfortably inside the input range. Output is set by the feedback divider working against a 0.8 V reference, so a small turn of the pot moves the rail a long way.

### WS2812B addressable LEDs

- [WS2812B datasheet](datasheets/compute/ws2812b-datasheet.pdf) - the one-wire bit timing, the reset gap, and the byte order

The timing table is basically the whole spec, since the driver is just a pulse train on PA8. The parts that matter: the reset gap between frames is anything above 50 us of low, and each pixel takes 24 bits in green-red-blue order, high bit first - not RGB, which is the easy way to get a display that lights up in the wrong colors.

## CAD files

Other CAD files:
cad/assemblies/comms/comms_assembly_v28.step
cad/assemblies/comms/rf/rf_assembly_v1.step
cad/assemblies/compute/compute_assembly_v79.step
cad/assemblies/compute/power/power_assembly_v8.step
cad/assemblies/compute/sensor/sensor_assembly_v3.step
cad/assemblies/gimbal/gimbal_assembly_v30.step
cad/assemblies/gimbal/rw/flywheel/flywheel_assembly_v7.step
cad/assemblies/gimbal/rw/rw_assembly_v8.step
cad/assemblies/ground_assembly_v6.step
cad/assemblies/satellite_assembly_v66.step
cad/printed/ground_plate_v8.step
cad/reference/actuation/MB1419-G431CBU6-B05_v3.step
cad/reference/comms/RFM95W v5_v1.step
cad/reference/compute/NUCLEO-F446RE--3DModel-STEP-56544_v5.step
cad/reference/ground/Pantalla OLED 0.96'' 128x64_v1.step
cad/reference/power/battery_4S_LiPo_v4.step
cad/reference/sensors/AS5600_v4.step
cad/printed/ground_cover_v17.step
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

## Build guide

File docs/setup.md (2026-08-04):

# Setup

## Prerequisites

Everything needed, and what each part is for. Only the first three are needed to run the host test suites; the rest are per-node, so a contributor who only touches flight software can stop after CMake.

| Tool | Needed for | Notes |
| ---- | --- | ----- |
| Git | everything | the vendored dependencies are submodules |
| [just](https://github.com/casey/just) | everything | task runner; `just` with no arguments lists every recipe |
| Python 3.12+ | tooling, SIL, HIL | packages declared in `requirements-dev.txt`, installed by `just deps` |
| CMake 3.20+ | flight software, firmware check | drives the host build and the ARM cross-build |
| A host C++17 compiler | flight software | MinGW-w64 g++ on Windows; any recent GCC or Clang elsewhere |
| [STM32CubeIDE](https://www.st.com/en/development-tools/stm32cubeide.html) | OBC firmware | owns the image that gets flashed, and bundles `arm-none-eabi-gcc` |
| STM32CubeProgrammer CLI | flashing the OBC | ships with CubeIDE; override its path with `CUBEPROG` |
| `arm-none-eabi-gcc` on PATH | `just obc-check` | CubeIDE bundles one but does not add it to PATH |
| [PlatformIO Core](https://platformio.org/) | ESC firmware | the VS Code extension installs it; override its path with `PIO` |
| A VISA backend | scope captures only | NI-VISA or equivalent, under `pyvisa`; nothing else needs it |

Three environment variables exist because their defaults are machine-specific: `CUBEPROG` and `PIO` are version-stamped install paths, and `OBC_STLINK` pins the Nucleo's ST-Link serial so an unpinned flash cannot land on the ESC. All three have working defaults in the justfile for this bench.

## Get the code

Clone the repo, then pull in the vendored dependencies - CMSIS, FreeRTOS, and ETL live under `vendor/` as Git submodules:

```bash
git submodule update --init --recursive
```

The Python tooling - the ground console, the SIL and HIL runners, the test suites - has its dependencies declared in `requirements-dev.txt`:

```bash
just deps
```

CI installs from that same file, so a dependency that is not declared there fails the build rather than working only on the machine it was added on.

## Firmware

Two boards run firmware, and each has its own recipes - `just` with no arguments lists them grouped by node.

**On-board computer** (Nucleo-F446RE, `obc/` + `fsw/`) builds with CMake and the `arm-none-eabi` toolchain, and flashes over the onboard ST-Link. CubeIDE can still open and build the project, but it is kept as a debugger rather than as the authority on the image - see the note under Tests. The board's UART comes back over the same USB cable as a virtual COM port.

```bash
just obc-build           # build the image
just obc-flash           # build, then flash over st-link swd
```

**Reaction-wheel node** (B-G431B-ESC1, `esc/`) is a PlatformIO project running SimpleFOC, flashed over its own onboard ST-Link.

```bash
just esc-build           # build the image
just esc-flash           # build, then upload over usb
```

### Camera register tables

The OV2640's JPEG bring-up is a few hundred SCCB register writes whose values the datasheet does not explain, so like every other driver in the wild the tables come from OmniVision by way of ArduCAM's library rather than being retyped. They live in `vendor/arducam/ov2640_regs.h`, byte-exact from upstream so it can be re-fetched and diffed:

```bash
curl -o vendor/arducam/ov2640_regs.h https://raw.githubusercontent.com/ArduCAM/Arduino/master/ArduCAM/ov2640_regs.h
```

Two small pieces bridge it into this tree, and neither touches the vendored file. `vendor/arducam/ArduCAM.h` is a local stand-in supplying the `PROGMEM` macro and the `sensor_reg` struct that upstream expects from the Arduino environment. `obc/Src/devices/ov2640_regs.cpp` maps upstream's table names onto the driver's, and is C++ rather than C because upstream is - some of its tables use brace initialization with no `=`, which is legal C++ and not legal C.

## Monitoring telemetry

The OBC streams CRC-framed telemetry over its virtual COM port. To decode it on the host:

```bash
just obc-monitor                      # decode telemetry frames
```

The port is found by the OBC's ST-Link serial number - the same one that pins the flasher - so neither has to be told which board it is talking to. Both nodes enumerate as ST-Link virtual COM ports, so with the whole stack plugged in there is otherwise no way to tell them apart, and monitoring the wrong board is the same class of mistake as flashing the wrong one. `just list-ports` shows what is attached.

The wheel node speaks the same frame format on its own link, so the bench driver both commands it and prints what comes back:

```bash
just esc-wheel 2.0 --hold             # 2.0 V on the q axis, held
just esc-wheel --watch                # listen only
```

## Commanding

The OBC accepts framed commands on the same links it sends telemetry out on - the ST-Link virtual COM port on the bench, and the PC6/PC7 header the radio lands on later. A serial port takes one program at a time, so commanding lives in the monitor rather than in a second tool competing for the link: type at the prompt while telemetry streams past.

```bash
just obc-monitor
```

Then `SET_MODE DETUMBLE`, `CAPTURE_IMAGE`, `CLEAR_FAULT WHEEL_DROPOUT`, or `?` to list what is accepted. Arguments are names rather than ids, resolved against the same catalogs the firmware is generated from, so a typo is refused on the ground instead of arriving as a valid-looking wrong id. Because the command goes out on the link the telemetry comes back on, the command, its ack, and the telemetry showing its effect all land in one stream in order. Tab completes command and argument names, and up-arrow recalls what was sent; telemetry scrolls above the prompt rather than over what is half typed.

The console holds the command link up on its own: after two seconds of an otherwise quiet uplink it sends a NOOP, which is what keeps `COMMAND_LINK_LOSS` from safing the vehicle without inhibiting the fault. It measures quiet rather than running a metronome, so a mission or a downlink pass - which is already talking - never has keepalives stacked on top of its chunk requests. `--no-keepalive` turns that off and lets the vehicle safe about five seconds into a silent run, which is how the fault itself gets demonstrated; `--read-only` disables transmit entirely.

Scripting uses the same syntax without the prompt - pipe commands in: `echo SET_MODE STANDBY | python tools/uart_monitor.py`.

## SIL scenarios

The SIL harness runs declared fault-injection scenarios against the flight software on the host - no hardware involved. See [verification.md](verification.md) for the harness, the evidence ladder, and the scenario catalog.

```bash
just sil                              # run the whole scenario suite, reports to docs/reports/sil/
just sil 1                            # or one scenario, by number or name
```

## Formatting

Formatting and linting run through pre-commit - clang-format for C/C++, ruff for Python - and the same checks run in CI, which also runs clang-tidy static analysis on the flight software. With Python and pre-commit installed:

```bash
pre-commit install   # once; the hooks then run on every commit
just format          # format and lint everything on demand
```

## Tests

Tests come in levels: unit suites (pytest for the Python tooling, CMake + doctest for the C++ flight software), the SIL scenario suite, and the HIL scenarios on the bench. `just test` runs everything machine-runnable, and the same suites run in CI; HIL needs the board, so it stays manual.

```bash
just test                # everything machine-runnable: all unit suites + the SIL suite
just unit                # both unit suites (or one: `just unit fsw`, `just unit tools`)
just sil                 # the SIL scenario suite (or one scenario: `just sil 5`)
just hil                 # the HIL campaign on the live board (or one: `just hil 2`)
just obc-check           # cross-compile and link the firmware, the same check CI runs
```

`obc-check` and `obc-build` are the same build - one CMake cross-build that produces the image `just obc-flash` writes to the board and the check CI runs. They were separate once, with CubeIDE's generated makefiles owning the flashable image, and that cost bench time twice: those makefiles list each source file explicitly and only the IDE regenerates them, so adding a source file broke the build with undefined references until someone refreshed and cleaned inside CubeIDE. CubeIDE remains useful as a debugger and can still build the project on its own, but it is no longer the authority. The build links rather than only compiling, because a symbol that compiles and never reaches the linker is a failure this project has hit twice.

Every test recipe takes an optional trailing `verbose` argument (`just test verbose`, `just unit fsw verbose`, ...) that switches to per-test names - through ctest for the C++ suite, `pytest -v` for the tooling, and per-check output for SIL.

`just unit fsw` does the configure, build, and run in one step.

## Working environment

Everything is built and run on Windows: firmware in STM32CubeIDE, git and tooling from PowerShell. Python handles the test and sim tooling as those parts come online.

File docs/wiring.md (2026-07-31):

# Wiring reference and build guide

The bench sheet: what wire goes where. `hardware.md` holds the reasoning, the parts, and the placement rules; `journal.md` holds how any of it went.

Everything below is built and wired, both radios included. What is left is the **PTC fuse and the battery harness**; the bench PSU's current limit stands in for the fuse until then.

## Things that silently destroy parts - read before touching a board

None of these announce themselves. A chip killed this way looks perfect, measures perfect, and does not work.

- **ESD.** A human feels ~3000 V; a chip dies at ~100 V. Ground yourself before handling a board, work off carpet, handle by the edges. A wrist strap is ~$8.
- **Never solder on a connected board.** Disconnect power, USB, every cable - a grounded board and a hot iron is an ESD path through you.
- **Ungrounded iron tips defeat an ESD-safe station.** With the iron hot, measure AC volts tip to mains earth: near zero is good, tens of millivolts is injecting into every joint.
- **Minimise rework near fine-pitch packages** - use screw terminals or existing connectors, and solder in one pass.
- **Connection order: ground and VCC first, high voltage last.** A chip with no valid ground reference passes current out through whatever pins are at a defined potential, typically the I2C lines.
- **First power-on always runs off the bench PSU with the current limit low, never the LiPo.** A
  current-limited supply turns a wiring mistake into a shrug; a 100C pack turns it into smoke.
- **Verify every rail with a meter before connecting a load.** This is the step that catches a
  reversed rail before it kills a board.
- **Adafruit INA228 jumper trap:** VBUS goes to **either** VIN+ (back jumper) **or** VIN- (a wire), **never both** - bridged, it shorts the shunt and puts system current through a signal trace. Preferred is the back jumper and no VBUS wire. Read any new breakout's pinout page before wiring it.

## Two rules that decide where caps and grounds go

**Bulk caps go where a device draws current in bursts, nowhere else.** No burst demand, no cap. Not to be confused with the 0.1 uF decoupling ceramics already fitted on every breakout.

| Location | Current behaviour | Cap |
| --- | --- | --- |
| nRF24 | ~115 mA TX bursts | **mandatory 10 uF at its own VCC/GND pins** - the #1 dead-link cause |
| LoRa | ~120 mA on TX | yes, 10 uF at VIN/GND |
| ESC input | motor PWM + regen transients | yes - the 470 uF/50 V |
| Slice 3V3 rail | MCU + sensors, steady | nice-to-have (10 uF fitted) |
| Sensor board | IMU ~4 mA, TMP 0.15 mA, steady | **no** - adding one would be cargo-culting |
| LED array | 20-40 mA dim | optional, skipped |

**Every ground arriving at a board joins one local rail** - except the sensor board, where grounds are per-cable back to the slice's rail. That is a star ground with the slice as the star point and every signal still has an adjacent return. Both are valid; do not rework the sensor board for consistency.

## The boards - where wires actually land

| Board | Mounting | What lands on it |
| ----- | --- | --- |
| Nucleo slice (**one board, both headers**) | 2x 2x19 female sockets, spanning CN7 and CN10 | everything - I2C1, SPI2, SPI3, all three UARTs, the LED, the radio control lines, and the supply rails |
| Sensor protoboard | screwed to compute plate | IMU, INA228, TMP117, ArduCAM - plus the I2C bus fan-out |
| ESC (B-G431B-ESC1) | friction-clamped | battery in, bulk cap, 3 motor phases, encoder I2C, UART to OBC |
| Buck converters (x2) | friction-clamped | 2 in / 2 out holes each |
| Power distribution protoboard | below the bucks | main power in, fans out to both bucks and the ESC; star ground |
| Gimbal plate | below compute | motor (3 phases), AS5600 (solder direct to its PCB holes) |

**One slice, not two (revised 2026-07-22).** The slice is now a single protoboard carrying both 2x19 female sockets, clipping onto CN7 and CN10 together with open board area between them. This **eliminates the 3V3 + GND bridge** - the rails and the signals are on the same board, so the old CN7-to-CN10 jumper (the most-likely-to-be-forgotten step in the build) no longer exists. Solder both sockets first and check the CN7-to-CN10 spacing seats without racking before committing all 76 pins.

**Three rails span the board**, and everything taps them: **3V3** (from CN7-16), **GND** (from CN10-9, with CN10-10/20 and a CN7 ground tied into the same rail), and the **SPI3 bus** (PC10/PC11/PC12 as single nodes, since the camera *and* both radios share it - never run separate wires per device back to the morpho pins). E5V (CN7-6) is separate: 5 V in from the buck, feeding nothing else on the board.

**The slice is a routing layer - the connector does not go where the pins are.** The morpho socket brings signals up at scattered positions (the IMU's four are CN10-30/28/26/16, not adjacent). Do not put the connector there. Instead: pick any clean row of N holes, solder the N-pin XH header there, and run **short board jumpers** from each scattered morpho pin to its header pin. The board gathers the scattered signals into one tidy header, so it stays **one connector per device** no matter how spread out its pins are - never split a device across two connectors. Power/ground pins do not route back to a specific morpho pin at all: they tap the nearest **3V3 or GND rail** hole, so only the signal pins need a jumper. (IMU example: 5-pin header, GND to the local rail, then SCK->CN10-30, MISO->CN10-28, MOSI->CN10-26, CS->CN10-16.)

**Connectors are JST-XH (2.5 mm), not PH.** XH latches (holds against vibration, releases with a tab press), its terminals are big enough to crimp reliably, and at 2.5 mm it seats in standard 2.54 mm protoboard - PH at 2.0 mm does not. One ratcheting tool crimps both, so the existing PH connectors at the ESC are not wasted. Use loose crimp terminals with a ratcheting crimper, never solder to pre-tinned pigtail leads (the crimp-backout failure mode).

## Power chain

```text
SOURCE (bench PSU for bring-up; 4S pack later)
  (+) --[PTC fuse]--[rocker switch]--> POWER DISTRIBUTION BOARD   (fuse + switch both Phase 8)
                                                  |
                              +-------------------+-------------------+
                              |                   |                   |
                          5V buck IN         3.3V buck IN         ESC VIN+
                              |                   |                   |
                          5V buck OUT        3.3V buck OUT       [470uF 50V cap
                              |                   |               across VIN+/GND,
                     Nucleo E5V (CN7-6)     radio 3V3 rail        at the terminals,
                              |             (LoRa + nRF24)        can anchored]
                    Nucleo onboard 3V3 reg
                              |
                     3V3 (CN7-16) --> slice 3V3 rail --> sensors
  (-) ------------------------------- STAR GROUND on the distribution board
```

Order on the positive lead is **fuse first (nearest the source), then switch**. The fuse protects the maximum length of wire that way.

### The distribution board itself

Two rails: a **+V rail** (main ~14.8 V) and the **star ground** - every ground in the satellite comes home here, none daisy-chained device to device.

| In / out | Wire | Endpoint | Connector | Colour |
| --- | ---- | --- | --- | --- |
| in | main + | PSU+/battery+ **via inline fuse** -> +V rail | XT60 (PSU clips for now) | red |
| in | main - | source- -> star ground | XT60 | black |
| tap | +V -> 5 V buck IN+ | on-board | solder | red |
| tap | +V -> 3.3 V buck IN+ | on-board | solder | red |
| tap | +V -> ESC feed + | to ESC | XT60 | red |
| tap | star -> each buck IN- and ESC feed - | on-board / XT60 | - | black |
| out | 5 V buck OUT+ -> Nucleo E5V | slice, CN7 end | JST-XH 2 | **red, banded 5V** |
| out | 5 V buck OUT- -> Nucleo GND | slice, CN7 end | same XH2 | black |
| out | 3.3 V buck OUT | radio protoboard 3.3 V rail | JST-XH 2 | red, black |

**Set each buck's output with a meter BEFORE any load is connected** - a buck trimmed to 12 V into the Nucleo E5V destroys it. Power the board from the PSU (14.8 V, limit ~200 mA), trim the 5 V buck to 5.0 V and confirm the 3.3 V buck reads 3.3 V, all with their outputs open. Verify main+ to star-ground reads **open** (no short) before ever applying battery power.

**Fuse: deferred to the Phase-8 battery harness, bare main + lead until then.** Blade fuses are the wrong scale here (bulky inline holders, loose spade fit). The selected part is a **Littelfuse RUEF300** PTC - 30 V, 3 A hold, radial through-hole, soldered in series with main+, auto-resetting. 3 A clears the ~1-2 A load and spin-up without nuisance-tripping, trips ~6 A, 100 A interrupt. Bourns MF-R300 and Littelfuse 30R300 are equivalents. **Not yet ordered** - see Carried work in `roadmap.md`. The bench PSU's current limit is the only protection until it is fitted, and **it must be fitted before the LiPo ever runs**.

**Switch and battery are accounted for, not built yet:** the switch is a series element in the main + lead (`battery+ -> fuse -> switch -> board`), inserted later by cutting that lead onto the switch tabs - leave slack. The main-bus INA228 relocation (sensor board to inline on this board's input, for total pack draw) is also Phase 8.

**Nucleo power, staged.** Keep the Nucleo on **USB (jumper on U5V)** while bringing up sensors - fewer variables, and you need USB for the console anyway. Only move the jumper to **E5V** and feed CN7-6 from the 5 V buck once you are deliberately testing the full power chain. The jumper selects one or the other; it will not power from USB while set to E5V.

**With JP5 on U5V, external 5 V on CN7-6 is ignored** - the buck reads a healthy 4.9 V while the MCU stays dark, and LD1 keeps blinking because the ST-LINK runs off USB regardless. **LD2 blinking green is the only "MCU is running" indicator**, not LD1. Measure at CN7-6 itself, not at the cable end.

**Suspect the newest cable before the silicon.** Three multi-hour debugs on this build were marginal cables, and the component tests came back clean every time.

**Every device gets its ground on the same connector as its power.** A powered device whose ground arrives on a signal connector floats when that connector is out, and hunts for a return through its I/O pins - on a shared bus that is enough to take a *different* device off the air. Cost a day when the camera did it to the INA228 (2026-07-26, mechanism found 2026-07-30; see `journal.md`).

**Crimp 24-26 AWG on the power connectors**, not 30 - XH terminals are rated 22-30 and grip poorly at the thin end. Check each crimp grips conductor and insulation, tug-test it, and confirm it clicks into its housing.

## Signal connections

Every pin below is the live map in `obc/Inc/board.h`; morpho holes are verified in the Board and rail reference at the end of this file.

### The ten connectors on the slice

**Physical layout - two columns, in numeric order top to bottom:**

```text
   [ CN7 socket ]                          [ CN10 socket ]
        left column                          right column
        (CN7-fed)                            (CN10-fed)
          3  camera SPI3                       1  sensor pwr+I2C
          7  5V in                             2  IMU SPI2
          8  radio SPI3 bus                    4  ESC UART
          9  LoRa control                      5  HIL UART
         10  nRF control                       6  LED
```

Each connector sits on the side of the board fed by its own socket, which keeps every jumper short.

Signals gather to each header via short board jumpers; power and ground tap the nearest rail. Max 5 pins, so 2/3/4/5-way XH stock covers everything with nothing to split. **(9) and (10) share the same wire colours - label them.**

Pins read **`<MCU pin>/<Morpho hole>`**, and the Morpho hole always carries its `CN7-` or `CN10-` prefix - the two headers both number into the 30s, so a bare number is ambiguous (PA9 is CN10-21 *and* PB7 is CN7-21).

| # | Connector | Wires | Pins | Colours |
| - | --- | ----- | ---- | --- |
| 1 | Sensor power+I2C (XH4) | 3V3, GND, SDA, SCL | rail, rail, PB9/CN10-5, PB8/CN10-3 | red, black, blue, yellow |
| 2 | IMU SPI2 (XH5) | GND, SCK, MISO, MOSI, CS | rail, PB13/CN10-30, PB14/CN10-28, PB15/CN10-26, PB12/CN10-16 | black, yellow, green, blue, white |
| 3 | Camera SPI3 (XH5) | GND, SCK, MISO, MOSI, CS | rail, bus, bus, bus, PB0/CN7-34 | black, yellow, green, blue, white |
| 4 | ESC UART (XH3) | TX, RX, GND | PA9/CN10-21, PA10/CN10-33, rail | blue, green, black |
| 5 | HIL UART (XH3) | TX, RX, GND | PC6/CN10-4, PC7/CN10-19, rail | blue, green, black |
| 6 | LED (XH3) | +5V, GND, DIN | CN7-18, rail, PA8/CN10-23 | red, black, blue |
| 7 | 5V in (XH2) | E5V, GND | CN7-6, rail | **red banded**, black |
| 8 | Radio SPI3 bus (XH4) | GND, SCK, MISO, MOSI | rail, bus, bus, bus | black, yellow, green, blue |
| 9 | LoRa control (XH3) | CS, DIO0, RST | PB7/CN7-21, PA0/CN7-28, PA1/CN7-30 | white, green, blue |
| 10 | nRF control (XH3) | CSN, CE, IRQ | PA4/CN7-32, PC2/CN7-35, PC3/CN7-37 | white, green, blue |

Rows 1-7 cross-check against the signal table below. **Rows 9 and 10 (the radios) do not** - their Morpho holes are inferred from the CN7 grouping rather than listed there.

**Components on the slice:** a **330-470 ohm resistor in series on the DIN line** of connector 6 (WS2812 data protection - put it here so the LED board gets a clean signal), and optionally a **1-10 uF cap across the 3V3/GND rails** for local decoupling. Nothing else: no pull-ups (the breakouts carry them), no level shifters (all 3.3 V), no transistors or diodes.

**Not on this slice:** radio 3.3 V power (that comes from the radio buck, which is why 8/9/10 carry no red wire). The LED's supply *does* come from here, but off **+5V at CN7-18**, not the 3V3 rail - three different power sources on this rig, do not mix them.

| Signal | MCU pin | Morpho hole | Slice | Goes to |
| --- | --- | --- | ----- | --- |
| I2C1 SCL | PB8 | CN10-3 | CN10 | sensor protoboard (bus fans out on-board) |
| I2C1 SDA | PB9 | CN10-5 | CN10 | sensor protoboard |
| SPI2 SCK (IMU) | PB13 | CN10-30 | CN10 | sensor protoboard -> IMU |
| SPI2 MISO (IMU) | PB14 | CN10-28 | CN10 | sensor protoboard -> IMU |
| SPI2 MOSI (IMU) | PB15 | CN10-26 | CN10 | sensor protoboard -> IMU |
| IMU CS | PB12 | CN10-16 | CN10 | sensor protoboard -> IMU |
| SPI3 SCK (camera) | PC10 | CN7-1 | **CN7** | sensor protoboard -> ArduCAM |
| SPI3 MISO (camera) | PC11 | CN7-2 | **CN7** | sensor protoboard -> ArduCAM |
| SPI3 MOSI (camera) | PC12 | CN7-3 | **CN7** | sensor protoboard -> ArduCAM |
| Camera CS | PB0 | CN7-34 | **CN7** | sensor protoboard -> ArduCAM |
| USART1 TX (ESC) | PA9 | CN10-21 | CN10 | ESC **RX** |
| USART1 RX (ESC) | PA10 | CN10-33 | CN10 | ESC **TX** |
| USART6 TX (HIL) | PC6 | CN10-4 | CN10 | USB-serial adapter RX (optional this session) |
| USART6 RX (HIL) | PC7 | CN10-19 | CN10 | USB-serial adapter TX (optional) |
| 3V3 out | - | CN7-16 | CN7 | feeds the slice 3V3 rail -> sensors |
| E5V in | - | CN7-6 | CN7 | from the 5 V buck (only when off USB) |
| GND | - | CN10-9/10/20, CN7 grounds | both | star ground |

**The camera splits across both slices** - its SPI3 and CS come off CN7, while its I2C config (SCCB) rides the shared I2C1 bus that arrives on CN10. That is not an error in the table.

**Cross TX to RX on the ESC link.** Two TX pins wired together is the classic dead-serial-link bug.

**USART2 (PA2/PA3) needs no wiring** - it is the ST-Link virtual COM port over the USB cable.

## The sensor protoboard - three connectors, and the bus fans out on-board

The I2C bus arrives **once** and is distributed on the board. Do not run separate I2C to the camera.

| Connector | Wires | Feeds |
| --- | ----- | ----- |
| 1. Power + I2C (JST-XH 4) | 3V3, GND, SDA, SCL | splits 4 ways for power, **3 ways for I2C** - INA228 (0x40), TMP117 (0x48), and the camera's SCCB (0x30) all share the one bus |
| 2. IMU SPI2 (JST-XH 5) | GND, SCK, MISO, MOSI, CS | the IMU |
| 3. Camera SPI3 (JST-XH 5) | GND, SCK, MISO, MOSI, CS | the ArduCAM |
| a. INA shunt (JST-XH 2) | VIN+, VIN- | **to the power board**, inline with main battery + (XH is rated 3 A against a <1.5 A peak) |

**Device pin details** (labels vary by breakout - these match the boards in use, and the IMU/INA/TMP mappings are proven by the working firmware):

- **IMU (SparkFun ICM-20948):** in SPI mode the I2C-looking labels change role - **SCL = SCK, SDA = MOSI, AD0 = MISO**, plus CS. VIN and GND to the rails. **Tie FSYNC to GND**; leave INT (data-ready, unused since the driver polls) and AUX_DA/AUX_CL (the internal path to the AK09916 magnetometer) unconnected.
- **TMP117:** VIN, GND, SDA, SCL to the rails. **INT** is a hardware limit-alert output - unused, the driver polls. ADDR unconnected defaults to 0x48.
- **INA228:** VIN/GND/SDA/SCL to the rails; VIN+ and VIN- out to the power board. **VBUS** is the bus-voltage sense pin and on this breakout it is isolated, connected to nothing - **wire it to VIN- locally on the sensor board** (the load-side tap, per the datasheet's high-side circuit). It never runs to the power board. Left floating, the chip measures a floating pin and reports nonsense, which is what tripped the bench UNDERVOLTAGE before the jumper was fitted. One VBUS-to-VIN- wire bypasses nothing - VBUS is a high-impedance input. ALRT unconnected. **VIN+, VIN- and VBUS all showing continuity is healthy**, not a short: the 15 mohm shunt reads as a dead short on any meter.
- **ArduCAM OV2640: all 8 pins are needed** - I2C configures the sensor, SPI reads the JPEG out of the FIFO, and neither does the other's job. Five leave the board on connector 3 (GND + the four SPI lines); VCC, SDA, SCL tap the board rails, **and so does a second GND** (added 2026-07-30, see the ground rule above). It is the only device fed from two runs, so it is the only one that can be powered without a reference - both grounds are deliberate.

Connectors 1 and 2 run to the **CN10 side** of the slice; connector 3 runs to the **CN7 side**.

**Chain the I2C sensors with STEMMA QT** - one JST-SH cable from the board's I2C fan-out into the INA228, a second from the INA228's other port to the TMP117. Power and I2C both ride the chain, so the TMP117 needs no separate wiring. The camera's SCCB taps the same bus from the protoboard's own holes.

**The INA228 measures the main battery bus (decided 2026-07-22).** The chip stays soldered on the sensor protoboard - it sits at the corner nearest the power distribution board, ~1 inch away - but its **VIN+ / VIN- shunt leads run to the power board, inline with the main battery positive**, after the fuse and switch:

```text
BATTERY+ --[PTC fuse]--[switch]--> INA VIN+ --[shunt]-- INA VIN- --> +V rail --> bucks + ESC
```

This works because the INA228's measurement front end handles up to 85 V **independently of its 3.3 V logic supply** - the chip runs at 3.3 V on the sensor board while its shunt terminals sit at battery potential (standard high-side sensing). Everything downstream of the shunt is measured, so bus voltage reads **actual battery state-of-charge** and current reads **total system draw** - which is what makes `UNDERVOLTAGE -> SAFE` a real demonstration rather than a theoretical one.

Earlier plans had the shunt inline with the 3V3 logic rail, which would have read a rock-stable 3.3 V that can never sag and ~75 mA of sensor draw - valid telemetry, but not the spacecraft power model. The objection to routing battery current near the magnetometer still holds in general; it is acceptable here only because the run is ~1 inch, at the board corner, with the IMU at the opposite (top, centred) end. **Use the heaviest wire on hand for the two shunt leads** - they carry full system current (~1-2 A, higher on motor spin-up); 26 AWG is acceptable at that length, 24 AWG or thicker preferred. The sensor board's own 3V3 rail is fed **directly** from connector 1, not through the shunt.

**Firmware follow-up:** the over/undervoltage thresholds are currently sized for a 3.3 V rail and must move to 4S LiPo values - ~16.8 V full charge, ~13.6 V undervoltage (3.4 V/cell), ~17.0 V overvoltage. Same logic, different constants. SHUNT_CAL is unchanged (same onboard 15 mohm shunt).

## Motor domain - ESC and gimbal plate

| Link | Wires | Layer | Connector |
| ---- | ----- | ----- | --- |
| Distribution -> ESC power | 2: VIN+, GND | intra (compute) | **XT60** (on hand) |
| Bulk cap -> ESC | across VIN+/GND | intra | soldered at the terminals, can anchored |
| ESC -> motor | 3: phase A, B, C | **inter** (compute -> gimbal) | direct solder + heat-shrink, or individual spades |
| ESC <-> AS5600 | 4: 3V3, GND, SDA, SCL | **inter** (compute -> gimbal) | JST-XH 4; solder direct into the AS5600's PCB holes at the far end |
| ESC <-> OBC | 3: TX, RX, GND | intra (compute) | JST-XH 3 |

**The AS5600 wires to the ESC, not the STM32.** The ESC closes the FOC loop locally and needs the encoder; the OBC only sends speed/torque commands over UART. This is the most common point of confusion in this build.

**The ESC's I2C is the Hall/encoder pads (J8), repurposed - there is no dedicated I2C connector.** On the B-G431B-ESC1 the Hall inputs map to PB6 (H1), PB7 (H2), PB8 (H3), and SimpleFOC uses **PB7 = SDA, PB8 = SCL** (`PIN_WIRE_SDA=PB7`, `PIN_WIRE_SCL=PB8`); H1/PB6 goes unused. On most revisions these are bare solder pads, not a plug.

**J8 pad order (confirmed against the user manual):** GND, 5V, Z+/H3, B+/H2, A+/H1. So SDA lands on **B+/H2**, SCL on **Z+/H3**, GND on the GND pad, and A+/H1 goes unused.

**The AS5600 breakout has no regulator**, and its R2/R3 are already the 10k I2C pull-ups - **add none**. In parallel with the ESC's ~10k on the Hall lines that gives ~5k effective, near the textbook 4.7k; more would over-pull the bus.

**Power the AS5600 from the ESC's J4 SWD pads (3.3 V), not J8's 5 V** - J8's supply is 5 V, and a 5 V-referenced pull-up puts 5 V on a 3.3 V part. **J4 pad order (UM2516 Table 6): 1 = SWDIO, 2 = SWCLK, 3 = MCU VDD (3V3), 4 = GND**, so 3V3 and GND are the two pads at one end, GND outermost. The manual does not say how pin 1 is marked, so **find orientation by continuity, not by probing voltage**: beep from any large ground to each end pad; the end that beeps is pad 4/GND and 3V3 is next to it. Backwards means soldering VCC onto SWDIO. The 3V3 rail is live whenever the board is powered, and the AS5600's ~6.5 mA is nothing to it. The encoder harness therefore lands on **two** ESC connectors: VCC on J4, SDA/SCL/GND on J8.

Once powered, SDA/SCL must idle at ~3.3 V - near 5 V means the Hall pull-ups reference 5 V and wants sorting first. Validate on an external supply, not USB alone; USB-only reports incorrect velocity.

**Confirm the J8 pad order against UM2516 or the board schematic before soldering** - pad order varies by revision.

Cut the motor's long phase leads down to a tidy length, but keep the encoder's 4-wire run **physically separated from the three phase wires**. Phase lines are switched PWM and AS5600 I2C is noise-sensitive.

### AS5600 checks

**Verified 2026-07-21** - STATUS masked 0x20, AGC 36, I2C scan found 0x36, one hand rotation read 6.26 rad against 6.28 theoretical.

**Air gap is tuned by AGC, not by eye.** Read register 0x1A: at 3.3 V the range is 0-128 and the target is **60-70** (low means too close, high too far). Move the magnet ~0.25 mm at a time, staying inside the 0.5-3 mm spec. Register 0x0B (STATUS) carries the magnet bits - **mask with 0x38**, since bits 0-2 and 6-7 read as garbage; **0x20** is the ideal result.

**Standalone bench check**, if the encoder ever needs re-verifying off the ESC: VCC-GND open and DIR-GND beeping unpowered, SDA-VCC and SCL-VCC each ~10k; ~5-10 mA draw at 3.3 V with SDA/SCL idling at 3.3 V and DIR at 0 V; then probe the analog `OUT` pin while rotating the magnet a full turn - it must sweep smoothly and wrap exactly once. That last test covers the chip, the joints, the magnet and the gap together.

**Trim all solder tails flush.** A screw is a floating conductor; the moment a second tail touches it, it bridges two nets.

## The ground station box

One Feather M0 RFM95 plus two modules. The LoRa radio is on the Feather, so only the nRF24 and the
display need wires, and the nRF24 shares the SPI bus the LoRa already uses.

**Taken by the onboard LoRa - do not reuse:** pin 8 (CS), pin 4 (RST), pin 3 (DIO0), and
SCK/MOSI/MISO. Leave **pin 9** alone as well: it is A7, the battery-voltage divider.

| Module | Signal | Feather pin | Colour |
| --- | --- | --- | --- |
| nRF24 | VCC | 3V3 (**never 5 V**) | red |
| nRF24 | GND | GND | black |
| nRF24 | SCK | SCK | yellow |
| nRF24 | MOSI | MOSI | blue |
| nRF24 | MISO | MISO | green |
| nRF24 | CSN | 10 | white |
| nRF24 | CE | 11 | blue |
| nRF24 | IRQ | not connected - the driver polls | - |
| OLED 1 (status, 0x3C) | VCC | 3V3 | red |
| OLED 1 (status, 0x3C) | GND | GND | black |
| OLED 1 (status, 0x3C) | SDA | SDA | blue |
| OLED 1 (status, 0x3C) | SCL | SCL | yellow |
| OLED 2 (payload, 0x3D) | VCC, GND, SDA, SCL | the same four pins, in parallel | as above |

- **10 uF across the nRF24's own VCC/GND**, as close to the module as it goes.
- **Add no I2C pull-ups.** The SSD1306 modules carry their own and the Feather has none. Two
  panels means two sets in parallel, which is fine on a bus this short.
- **The second OLED must be strapped to 0x3D** before it goes on the bus - a jumper or a moved
  resistor on the back of the module, per its silkscreen. Two panels on one address is one address
  answering twice, and the bus reads as a single confused display rather than as an error.
- The second panel is optional in firmware: it is probed at boot and skipped if nothing answers.
  The console's `GROUND` line reports `oled x1` or `oled x2`, so an unstrapped second panel is
  visible rather than merely puzzling - two modules on 0x3C both draw the status screen, which
  looks like a duplicated display rather than like a mistake.
- **Both antennas on before power** - the nRF24's SMA stub, and a 78 mm wire on the Feather's ANT
  pad (a quarter wave at 915 MHz). Two radios here can transmit.
- Whole box draws ~87 mA receiving against a 600 mA regulator, so USB alone runs it.

## Intra-layer vs inter-layer at a glance

**Inter-layer (must unplug to separate plates):**
- compute -> gimbal: 3 motor phase bullets + the encoder JST-XH 4
- compute -> comms: LED JST-XH 3, then the radio connectors

**Everything else is intra-layer**, on the compute plate: the slices, sensor protoboard, ESC, both bucks, and the distribution board.

## Harness bundling and routing

| Bundle | Wires | Notes |
| --- | ----- | ----- |
| A - sensor board <-> CN10 side | power+I2C (4) + IMU SPI2 (5) | fine together: all 3.3 V logic, one destination |
| B - sensor board <-> CN7 side | camera SPI3 (5) | own bundle, other socket |
| C - OBC <-> ESC UART | TX, RX, GND (3) | own small bundle |
| D - distribution -> ESC power | VIN+, GND (2) | twist the pair, keep off the signal side |
| E - motor phases | A, B, C (3) | twist all three, isolated; the one in the gimbal channel |
| F - encoder -> ESC | 3V3, GND, SDA, SCL (4) | bundle together, route away from E |

- **Never bundle the motor phases (E) with anything, least of all the encoder (F).** The phases are
  switched PWM carrying amps; AS5600 I2C is weak, slow, open-drain, and exactly what that corrupts.
- **Twist each conductor with its return.** Power pairs and the three phases twist so the currents
  cancel. Signals return in ground, so ground rides in the same bundle - the encoder's four wires
  twist as one, never split into a VCC+GND pair and an SDA+SCL pair.
- **Cross noisy and signal bundles at 90 degrees, never parallel.** Matters more than separation,
  which is scarce inside 100 mm.
- **Service loop at every connector**, bundle anchored a couple of cm back so vibration works the
  anchor and not the joint, and nothing able to reach the flywheel's swept volume.
- Ties: hook-and-loop while building, waxed lacing cord for the final tidy. Not zip ties - they
  bite insulation and servicing means cutting them off.

## The comms plate

Built 2026-07-26. Wiring is done; the drivers are not.

- **LED array:** 3 WS2812 beads chained on their small protoboard (D1 -> D0 down the row), one **JST-XH 3** (+5V, GND, DIN on **PA8 / CN10-23**) crossing up from the CN10 side. Series resistor 330-470 ohm on the first D0. **Powered at 5 V (CN7-18), with 3.3 V data** - the beads are spec'd 3.5-5.3 V, so a 3.3 V supply is below minimum and they simply do not light (found the hard way 2026-07-26). 3.3 V data into a 5 V-powered bead is the intended arrangement and needs no level shifter; if it ever turns flaky, a series diode on the 5 V feed drops it to ~4.4 V and pulls the input threshold down with it. **Bead 0 is the one nearest the data connector** - MODE, then FAULT, then LINK down the chain.
- **Radios:** built as a self-contained module on their protoboard - a shared **SPI3** bus (SCK/MISO/MOSI each one node, wired to both radios) plus a 3.3V and GND rail. Power (3.3V+GND) comes from the **radio buck**, signals from the **CN7 side** - two different destinations, so the down-going pigtails split by destination: power XH2 (to buck), SPI3 bus XH4 (SCK/MISO/MOSI/GND to CN7), LoRa control XH3 (CS/DIO0/RST), nRF control XH3 (CSN/CE/IRQ).

  | RFM95 LoRa (3.3V-only board) | -> | nRF24L01+PA+LNA | -> |
  | --- | --- | --- | --- |
  | VIN -> 3.3V rail | | VCC -> 3.3V rail (**10 uF cap right here**) | |
  | GND -> GND rail | | GND -> GND rail | |
  | SCK/MISO/MOSI -> shared bus | | SCK/MOSI/MISO -> shared bus | |
  | CS -> PB7 | | CSN -> PA4 | |
  | G0 (DIO0) -> PA0 | | CE -> PC2 | |
  | RST -> PA1 | | IRQ -> PC3 | |
  | EN -> tie 3.3V (always on) | | | |
  | G1-G5 -> unconnected | | | |

  The nRF24 10 uF cap at its VCC/GND is the #1 dead-link fix; add one at the LoRa VIN too. Never key EN or transmit without the antenna attached.

## Pin reservations - do not consume these

| Pin | Hole | Reserved for |
| --- | ---- | --- |
| PA8 | CN10-23 | WS2812 LED data |
| PB7 | CN7-21 | radio control line |
| PA0 | CN7-28 | radio control line |
| PA1 | CN7-30 | radio control line |
| PA4 | CN7-32 | nRF24 CSN |
| PC2 | CN7-35 | nRF24 CE |
| PC3 | CN7-37 | nRF24 IRQ |

The two radios need six GPIOs - LoRa (CS PB7, DIO0 PA0, RST PA1) and nRF24 (CSN PA4, CE PC2, IRQ PC3) - and the original reserved block only had four spares once **PB0 (CN7-34) went to the camera CS**. **PC2 (CN7-35) and PC3 (CN7-37)** close the gap: both free, both plain GPIO, both confirmed on CN7. Still avoid PA13/PA14 (SWD), PB11 (not bonded out on the LQFP64), and PB3 if SWO trace is ever wanted.

## Wire colors

Read the scheme by **role**, not by signal name, and every one-off line places itself with no new colours and no repeats inside a single cable.

| Colour | Role | Covers |
| --- | ---- | --- |
| red | power | 3V3, 5V (**band any 5 V wire** - feeding it to a 3.3 V part is fatal) |
| black | ground | GND |
| yellow | clock | SCK, SCL |
| blue | out (MCU drives) | MOSI, SDA, UART TX, WS2812 DIN, radio RST, nRF24 CE |
| green | in (MCU reads) | MISO, UART RX, LoRa DIO0, nRF24 IRQ |
| white | select | CS, CSN |

**26 AWG throughout on the slice** - no exceptions. Even the E5V feed (the Nucleo's full draw) and the 3V3 bridge (all of CN10's sensor current) are well within it.

## Things that are NOT connected (common confusions)

- The **AS5600 does not touch the STM32** - it is the ESC's encoder.
- The **console UART needs no wires** - it is the ST-Link VCP over USB.
- The **bulk cap lives only at the ESC** - not on the sensor board, not on another plate.
- The **3.3 V buck powers only the radios** - never the Nucleo, never the sensors.
- **No I2C pull-up resistors to add** - the breakouts carry their own.
- **No level shifters, transistors, or flyback diodes anywhere** - everything is 3.3 V logic and the ESC handles the motor internally.
- The **camera needs no separate I2C run** - it taps the shared bus on the sensor protoboard.

## Board and rail reference

Physical holes are ST morpho positions (CN7 / CN10), verified against UM1724 (Table 19 Arduino, Table 29 morpho, Figure 24 board pinout) and the STM32F446 datasheet DS10693 Table 11 (alternate-function map). The live pins also exist in `obc/Inc/board.h`, the firmware's pin-map header.

### Rails

One rail, bused - never one MCU pin per device, and never a GPIO as a supply.

- **3V3 sources:** CN7-16 (morpho) or CN6-4 (Arduino power header). Pick one, run it to a 3V3 rail on the slice, tap every 3V3 part off that rail.
- **5V sources:** CN7-18 (morpho) or CN6-5 (Arduino).
- **Do not mistake these for 5V outputs:** **E5V (CN7-6) is an input** - it powers the whole board from an external 5 V supply. **U5V (CN10-8)** is the 5 V coming from the ST-Link side of the USB. Neither is a general-purpose 5 V tap; use +5V (CN7-18 / CN6-5).
- **Ground:** CN10-9 / CN10-10 / CN10-20 sit right next to the sensors - use one as the GND rail and tie it to the CN7 ground so everything shares one reference.
- **Never power a sensor from a GPIO held high.** A GPIO sources only a few mA, the whole port shares a current ceiling, and the voltage sags under load. Power comes from the rails; GPIOs carry logic only.

### Current budget

The digital sensors are a rounding error on the Nucleo's 3V3 (the onboard regulator path supplies a few hundred mA after the MCU's share):

| Rail | Part | Typical draw |
| ---- | ---- | --- |
| 3V3 | ICM-20948 (accel+gyro+mag) | ~3-4 mA |
| 3V3 | INA228 | ~1 mA |
| 3V3 | TMP117 | ~150 uA |
| +5V (CN7-18) | WS2812 status LEDs (3 beads, chained) | ~60 mA per bead at full white; run dim (~10-20%), so a few mA each |

The radios are the real load - the nRF24 PA+LNA pulls ~115 mA in bursts, LoRa ~120 mA on TX. They run off the dedicated battery-fed 3.3 V buck, never the Nucleo's 3V3.

**The motor is not on these rails.** The ESC and motor run off the battery (14.8-16.8 V) - never the Nucleo's 3V3 or 5V. Only two things cross between the OBC and the ESC: the UART link and a shared ground reference.

### Don't-touch and gotchas

- **PA5 is the LD2 LED**, so SPI1's default pins (PA5/PA6/PA7) are out. That is why the IMU is on SPI2 and the camera/radios on SPI3, not SPI1.
- **PB11 is not bonded out on the F446RE** (LQFP64) - Figure 24 shows CN10-18 as NC even though the shared morpho table lists PB11. USART3 on PB10/PB11 is a dead end.
- **PA13 / PA14 are SWD** (ST-Link debug) - leave them alone or you lose flashing and debug.
- **PA2 / PA3 are the USART2 VCP** - they reach the laptop over USB but are isolated from the header pins by default solder bridges (UM1724). Use USART6 (PC6/PC7) for anything you need to probe on a scope or analyser.
- **PB3 is SWO** - avoid it if trace output is ever wanted.

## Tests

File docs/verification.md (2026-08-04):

# Verification and validation

How claims stay tied to evidence. Requirements are written before the code, each carries a status naming the strongest evidence in the repo, and nothing is described as working somewhere the repo cannot show it.

## The evidence ladder

A status in [requirements.md](requirements.md) names the highest level reached:

planned -> in progress -> unit-verified -> SIL-verified -> bench-verified -> HIL-verified

Unit tests check logic in isolation (doctest, host). SIL runs the real executive end to end against declared scenarios, still on the host. Bench and HIL run the same claims on the STM32 with real timing and real links. A claim climbs only when the artifact for that level exists, and the status names it.

## Traceability

Requirement ids run through the whole chain: stated in [requirements.md](requirements.md), cited in code, named in unit-test cases, declared by scenarios, stamped into mode-transition log rows, and recorded in reports. `just trace` checks the chain.

## SIL

Two pieces, kept separate:

- **The shim** (`fsw/sil/sil_shim.cpp`) links the unmodified flight-software library, reads a per-cycle timeline on stdin, runs `Executive::cycle()` with injected time, and prints everything observable as tagged lines. It grades nothing.
- **The runner** (`tools/sil_runner.py`) compiles the scenario YAML, drives the shim, decodes telemetry through the same codec the ground tools use, grades observed against expected, and writes the report. No flight logic, no scenario-specific code (REQ-VV-001).

Time is injected, so a 2-second scenario runs in milliseconds and is exactly reproducible. What SIL cannot cover: real-time behavior, link timing, ISR interactions, anything electrical.

```
just sil                # the whole suite
just sil 5              # by number...
just sil command_loss   # ...or by name fragment
```

Exit 0 all passed, 1 a scenario failed, 2 harness error. Reports are written either way.

### Catalog

| ID | Title | Verifies | Report |
| -- | ----- | --- | --- |
| SIL-001 | undervoltage drives safe mode | REQ-FAULT-002 | [SIL-001.md](reports/sil/SIL-001.md) |
| SIL-002 | illegal-in-mode command is rejected and acked | REQ-CMD-001, REQ-CMD-003 | [SIL-002.md](reports/sil/SIL-002.md) |
| SIL-003 | degraded fault latches without entering safe mode | REQ-FAULT-005 | [SIL-003.md](reports/sil/SIL-003.md) |
| SIL-004 | transient bad samples are debounced away | REQ-FAULT-004, REQ-FAULT-009 | [SIL-004.md](reports/sil/SIL-004.md) |
| SIL-005 | command-link silence trips the dead man into safe mode | REQ-CMD-002 | [SIL-005.md](reports/sil/SIL-005.md) |
| SIL-006 | ground recovers the spacecraft from safe mode | REQ-FAULT-010, REQ-MODE-006 | [SIL-006.md](reports/sil/SIL-006.md) |
| SIL-007 | unreachable mode target refused at validation | REQ-MODE-004, REQ-CMD-006 | [SIL-007.md](reports/sil/SIL-007.md) |
| SIL-008 | safing wins a same-cycle conflict with an accepted command | REQ-EXEC-001 | [SIL-008.md](reports/sil/SIL-008.md) |
| SIL-009 | gyro dropout retreats POINTING to STANDBY | REQ-FAULT-005 | [SIL-009.md](reports/sil/SIL-009.md) |
| SIL-010 | power dropout retreats DOWNLINK to STANDBY | REQ-FAULT-005 | [SIL-010.md](reports/sil/SIL-010.md) |
| SIL-011 | detumble nulls a spinning platform without saturating the wheel | REQ-ADCS-001, REQ-ADCS-003 | [SIL-011.md](reports/sil/SIL-011.md) |
| SIL-012 | a saturated wheel is announced, retreats the vehicle, and is unwound in standby | REQ-ADCS-003 | [SIL-012.md](reports/sil/SIL-012.md) |
| SIL-013 | detumble declares itself done and returns to STANDBY | REQ-MODE-011 | [SIL-013.md](reports/sil/SIL-013.md) |
| SIL-014 | a spun-up vehicle detumbles itself and resumes | REQ-MODE-012 | [SIL-014.md](reports/sil/SIL-014.md) |
| SIL-015 | the plant model's friction matches the rig's measured coast-down | REQ-ADCS-001 | [SIL-015.md](reports/sil/SIL-015.md) |

SIL-011, SIL-012 and SIL-015 run against the plant model (`fsw/sil/plant.cpp`), so they are the only ones whose result depends on measured hardware numbers - inertias from CAD, friction fitted to two platform coast-downs at different speeds (2026-07-31 and 2026-08-04). That dependency is not a weakness of the scenarios, it is the thing they are for: when the friction fit was changed, SIL-011 failed the same day and the vehicle's stated recoverable-upset figure moved with it.

**SIL-015 is the one that checks the model against the world rather than against itself.** It coasts the platform in SAFE - no torque, no autonomous entry - which is the same procedure run on the rig, and `tools/overlay.py` plots the two decays together and prints both decelerations:

```
just overlay --rig docs/data/rig_coast_safe_2026-08-04.csv --scenario SIL-015
```

The recorded bench runs live in `docs/data/`, captured with `uart_monitor.py --record`. As of 2026-08-04 the model sheds 141 deg/s^2 against the rig's 161 - a 14% disagreement, which is about as close as a two-point friction fit and a hand-spun platform deserve. Its value is not the number: a model checked only against its own scenarios will absorb a bad measurement silently, and this comparison is what caught one doing exactly that. See [architecture.md](architecture.md).

### Writing a SIL scenario

```yaml
id: SIL-001
title: undervoltage drives safe mode
verifies: [REQ-FAULT-002]
timeline:
  - { t: 100, cmd: { name: SET_MODE, arg: 1, seq: 1 } }
  - { t: 1400, fault: { name: UNDERVOLTAGE, bad: 1 } }
  - { t: 2000 }
expect:
  mode_log:
    - { to: SAFE, trigger: FaultEntry, req: REQ-FAULT-002 }
  acks:
    - { seq: 1, accepted: true }
  final:
    mode: SAFE
    faults_set: [UNDERVOLTAGE]
```

Each timeline step is one executive cycle at time `t` (ms, strictly increasing) and may carry fault samples, one command, both, or nothing. Names come from the catalogs in `common/protocol/state.hpp`. `mode_log` rows match in order and field by field, `acks` match by sequence number against decoded telemetry, `final` checks the end state. Every frame is CRC-checked unconditionally.

Two things to know. The command-loss timer is always armed, so any timeline running quiet past t=5000 safes on COMMAND_LINK_LOSS - keep scenarios short or feed NOOP keep-alives. And do not grade on the final mode alone: pin the trigger and requirement id, because SAFE reached for the wrong reason is still wrong.

## HIL

Same flight software on the real STM32 over the live serial link, scenarios under `fsw/hil/scenarios/`. There is no input timeline - stimuli are bench actions declared as an operator instruction - and the only observable is the telemetry stream, which is the constraint a real ground station works under.

Inside `tools/hil_runner.py`, a pure link monitor owns every health decision (link up, loss against the heartbeat timeout, recovery, sequence gaps, timing) and takes time as an argument, so it is unit-tested with injected time. Around it is a serial pump that only moves bytes. Grading and reports share SIL's core and exit-code contract.

```
just hil                 # the whole campaign
just hil 2               # by number, name fragment, or path
just hil-scope 1 frame   # file a scope capture
```

HIL needs the bench, so it is manual and never runs in CI.

### Catalog

| ID | Title | Verifies | Report |
| -- | ----- | --- | --- |
| HIL-001 | heartbeat timing on the live link | REQ-VV-003, REQ-TLM-002, REQ-TLM-003 | [HIL-001.md](reports/hil/HIL-001.md), [scope captures](reports/hil/HIL-001-scope.md) |
| HIL-002 | link loss declared and recovery observed | REQ-VV-003 | [HIL-002.md](reports/hil/HIL-002.md) |
| HIL-003 | scheduler smoke - every task alive, stacks intact, watchdog fed | REQ-RT-002, REQ-RT-003, REQ-WDG-001 | [HIL-003.md](reports/hil/HIL-003.md) |

Three things about these that are not obvious from the reports:

- HIL-001's heartbeat band is 0.9-1.15 s and is deliberately not tighter. The board measures 1.000 s, but the window has to absorb USB CDC arrival jitter on the host, which is not the board's fault to be graded on.
- HIL-003's `stack_free_min` is a floor, not a measurement. Stacks are sized at 4-5x the observed peak, so dipping under 64 free words means a task's work grew and the sizing needs redoing (REQ-RT-003).
- The watchdog actually biting cannot come from HIL-003 - a run that resets has stopped being a smoke test. It was demonstrated separately by removing the control task's check-in, after which the board reset and reported `reset=iwdg-watchdog`.

Scope captures are the one kind of HIL evidence the runner cannot produce. They are taken at the bench, filed under `docs/reports/hil/img/`, and written up in a hand-authored companion (`HIL-001-scope.md`) beside the generated report, which the runner overwrites on every rerun.

### Writing a HIL scenario

```yaml
id: HIL-002
title: link loss declared and recovery observed
verifies: [REQ-VV-003]
duration_s: 45
operator: about 10 s in, hold the reset button down for about 10 s, then release
expect:
  link: recovered
  outage_s: { min: 5.0 }
```

`duration_s` is the observation window; `operator` is printed at start. Expectations: `link` (`up` = came up once and never dropped, `recovered` = one loss and one recovery), `seq_gaps`, `crc_rejects`, `period_s` (a band every measured period must sit in), `outage_s`, `tasks_reported` (the exact set of task names in every report), `watchdog` (`fed` = no report withheld the pet), `stack_free_min`. An expectation left out is not graded - HIL-002 omits `seq_gaps` because the reboot's counter restart is expected.

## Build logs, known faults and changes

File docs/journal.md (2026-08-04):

# Journal

Two things worth keeping: what was learned the hard way, and a dated record of what was proven
when. Reasoning for the current design is in `architecture.md`; what is left to build is in
`roadmap.md`.

## Lessons

Each of these cost real time and would change what someone does next.

**Suspect the newest cable before the silicon.** Three multi-hour debugs on this build were
marginal cables, and the electrical tests on the components came back clean every time, because
the components were fine.

**A powered device with no ground reference takes down its neighbours.** The camera's ground
arrived only on its SPI3 connector; unplugging that left it floating at ~500 mV and hunting for a
return through its SCCB pins, which pushed the INA228 off the shared I2C bus. Cost a day in July
and was only explained a week later. Every device gets power and ground on the same connector.

**A green build says less than it looks.** `file(GLOB)` is evaluated at configure time, so a new
source silently linked against the old file list - three sessions lost before `CONFIGURE_DEPENDS`.
And `--gc-sections` drops code nothing calls: the whole LoRa driver compiled and was absent from
the image, with `nm | grep` the only symptom.

**An open-loop test checks what a controller says; only a closed loop checks what it does.** The
detumble law had its sign backwards - commanding a wheel torque whose reaction accelerated the
platform - and every unit test passed, because a formula test cannot tell which way a reaction
pushes.

**`||` short-circuits, so a state-machine step on its right only runs sometimes.** `rfm95_tx_done`
is what returns the radio to receive; behind `!pending ||` it ran once a second and the vehicle
was deaf almost continuously. Side effects do not belong in conditions.

**Two correct instructions can compose into a trap.** The bias needed two still seconds at boot;
the compass needed a calibration turn right after power-up. An operator doing both in the told
order poisoned the bias with the turn, and the vehicle wedged itself detumbling a spin that
existed only in the arithmetic. Calibration steps that share a clock must be checked against each
other, not just each against the hardware.

**Never pace a half-duplex transmission off the other end's frames.** A request triggered by the
vehicle's own status frame launches phase-locked to the vehicle's transmit schedule, and if the
phase is wrong it is wrong every time - eight consecutive selective-repeat requests landed in the
vehicle's deaf window. The command retries already knew this and used 0.7 s against a 1 s beacon;
the requests were written a week later and stepped straight into it.

**A control gain belongs to the plant, not to the mode using it.** POINTING's inner loop is
DETUMBLE's law with a moving setpoint, and it was given a gain twelve times the one the rig had
already accepted, because the slew needed more torque to break the bearing loose. The platform
does not care which mode is asking - it oscillated at 215 deg/s. The two gains are one gain and
are now pinned together in the header with the reason.

**Friction is not answered by feedback.** Below the bearing's breakaway the platform does not move
at all, and the gain large enough to clear it is the gain that oscillates - the two windows do not
overlap, so no amount of tuning finds a value in between. What works is a constant: a fixed
feedforward in the direction of the error, applied only while the platform is stopped, which
supplies authority without adding any loop gain. That took POINTING from thrashing to converging
in one change, after two sessions of tuning the wrong knob.

**A measurement taken through a slower stream than the event is not a measurement.** The
breakaway sweep asked the ground to compare the heading before and after each pulse. The pulse
lasts half a second, the platform breaks loose and friction stops it inside a second, and the
radio delivers one attitude frame per second - so a 13 deg/s jolt was recorded as "no movement"
while the heading crept visibly across the whole sweep. The vehicle watches its gyro ten times
faster and simply knows; it reports the peak now instead of the ground guessing from samples.

**The bench rig is part of the plant, and its cables are a spring.** A breakaway sweep looked like
friction until the platform kept returning to where it started after every pulse - dissipation
does not do that, elasticity does. The USB cable feeding the board was a torsion spring across the
rotating joint. Any attitude measurement taken with something plugged into the vehicle is
measuring the tether too, which is the reason the rig is built to run on battery.

**A signal that is merely plausible is not a signal that is right.** The control path read gyro z
as yaw for five weeks, and z read plausibly - noise at rest, small wiggles when touched - because
cross-coupling gives every axis a shadow of the real motion. Only spinning the platform and
comparing all three channels showed the spin lived on x. Check which channel actually carries the
physics before trusting the one the datasheet suggests.

**A one-way link needs repetition, not a better error rate.** 88% packet delivery sounds like a
working link and delivered zero images: a frame spans three packets, an image needs every frame,
and there is no ack to retransmit against. Losses fall in different places each pass, so sending
the same frame three times is worth far more than the arithmetic suggests.

**Two PA+LNA radios a foot apart is a receiver problem, not a range problem.** At full transmit
power delivery was 39%; at minimum it was 88%. An overloaded low-noise amplifier does not degrade
gracefully, it stops decoding, so the symptom looks like a weak link and the fix is less power.

**A receiver's fifo depth is a rate limit on the transmitter.** The nRF24 holds three packets and
a frame spans three, so anything the ground could not collect in time took a whole frame with it -
588 packets sent, 379 received, one frame decoded. Independent packet loss would have left a
quarter of the frames intact; losses in runs left none. Pace the sender to what the receiver can
take.

**A health message sent once, at boot, is not observability.** The ground station said whether
its radios came up exactly once, before anyone had opened a terminal - so a dead payload receiver
and a working one hearing nothing produced identical evidence for three sessions, while the
vehicle transmitted whole images into it. Anything that can be false later has to be said again.

**A shadow copy of a byte stream drifts from the parser reading it.** The ground station buffered
received bytes to forward "the frame the parser just finished", but nRF24 packets are padded to 32
and a frame is 70, so the padding accumulated in the shadow buffer and every forwarded frame was
padding plus a truncated frame. No image ever reassembled. The parser already knows the frame -
re-encode from it and there is nothing to drift.

**Half duplex means a scheduling constant decides how deaf the vehicle is.** The radio cannot hear
while transmitting, and leaving the return-to-receive to whoever next polled put the telemetry
task's 50 ms idle wait on top of 57 ms of air time. One uplinked command in six was lost. The
transmit now waits for its own completion, and the ground retransmits until acked.

**A completion flag reads zero before the first operation.** Gating the first transmit on "has the
last transmit finished" deadlocks forever. The beacon never sent a single packet.

**A task that gains work needs re-measuring, and nothing prompts you.** The health task went under
its stack floor twice in two days, the second time immediately after writing that lesson down. The
number sits in every TASKS line until somebody reads it.

**A checker only run against a passing repo has not been shown to catch anything.** The PAL
boundary check's first regex could not match `NVIC_EnableIRQ`, because `_` is a word character - so
every underscored form, which is how these names are actually written, passed silently.

**Read the vendor's source rather than reasoning from the register map.** Three separate camera
bugs were found by diffing against ArduCAM's own sequence after reasoning had failed.

**Estimates can be wrong in the direction that matters.** Guessed inertias put the wheel's
authority at 3.6 rad/s of platform rate; measured, it is 0.87. Two errors compounding, and every
conclusion drawn before the measurement was out by 4x.

**A fault with no responder is a catalog entry.** Observability first, response when there is
something to respond with.

**Dates come from `git log`, not memory.** Entries here drifted into the future more than once.

## Log

Dated evidence, newest first.

### Phase 8 - wireless link and ground station

### Phase 8 - the capstone

- **2026-08-04** - **The survey flew; the panorama did not.** One typed word - `survey 4 60` - and
  the vehicle pointed itself, captured, downlinked 400-odd chunks with selective repeat, parked in
  STANDBY to unwind its wheel, slewed, and did it again. Three frames landed, unattended, on
  battery, over the radio, with nothing plugged into the vehicle. The sequencing works.
  The picture does not. The frames came from roughly 0, 9 and 28 degrees against a commanded 0,
  20 and 40, because a slew that size runs the wheel out of momentum before it arrives - so they
  overlap almost completely and the stitched strip is three near-identical photographs rather than
  a swept scene. It was tempting to keep it anyway; a file called `panorama.jpg` that is not one
  is exactly the kind of claim this repo is built to not make, so the output and its frames were
  removed and REQ-PAY-006 says "in progress". The macro and the stitcher stay - what they need is
  bearing separation, and that is an actuator problem, not a sequencing one.
- **2026-08-04** - Three ground-side bugs stood between the survey and that result, and all three
  were the same shape: **believing something held when it did not.**
  The aim step trusted an in-band flag that was still describing the *previous* bearing, so the
  first attempts shot twice in the same place; the fix is a handshake, waiting for the vehicle to
  echo the target it is holding. The keepalive treated selective-repeat chunk requests as "the
  link is busy", but those never reach the command handler, so the ground chattered for nine
  seconds while the vehicle heard silence and safed at exactly five. And momentum dumping was
  written against the ESC's velocity, which reads +/-3 rad/s at a standstill - so a vehicle idling
  in STANDBY spun its wheel *up* on noise, and every leg started from an arbitrary wheel state.
  The last one is the sharpest: the magnetometer gate had learned that exact lesson an hour
  earlier and switched to reading the wheel's angle. Knowing a signal is untrustworthy does not
  help if the next thing you write reaches for it anyway.

### Phase 7 - closing the loop on the rig

- **2026-08-04** - **The wheel can be emptied now.** REQ-ADCS-003 had a clamp and no answer: the
  rig had shown a saturated wheel holding full commanded torque for fifteen seconds with the rate
  pinned at zero, and nothing in telemetry said why. `WHEEL_SATURATED` latches at 90% of the
  wheel's measured top speed, retreats the steering modes to STANDBY, and STANDBY unwinds the
  wheel against the platform's own bearing - any torque under breakaway spins the wheel down
  without moving the body, so the stiction that makes pointing hard is what makes the wheel
  rechargeable. The retreat goes to STANDBY *because* that is where the cure lives.
  Closing it turned up a gap in the harness worth its own note: the plant has modelled the wheel's
  speed since it was written and never reported it to the flight software, so every scenario ran
  with the actuator's own state invisible. An actuator a simulation steers but does not report is
  one whose failure modes cannot be graded - SIL-012 went from 7 checks to 9 the moment the shim
  passed it through.
- **2026-08-04** - **The controller earns its keep: 2.5x friction, measured.** The same ~90 deg/s
  spin was run in SAFE, where no torque is commanded and autonomous entry is off, and in STANDBY,
  where it pulls the vehicle into DETUMBLE. Friction alone: 161 deg/s^2. With the wheel:
  412 deg/s^2. That closes the gap REQ-ADCS-001 had been carrying - a platform that stops itself
  makes "it stopped" worthless as evidence, and the only way through it is a controlled
  comparison. None of it was measurable at the heartbeat's 1 Hz; the entire decay was one sample
  until the attitude telemetry moved to the control rate.
- **2026-08-04** - **The plant model's friction was right all along, and it took two bad
  "corrections" and an overlay to find that out.** The morning's breakaway sweep was read as
  bearing stiction and coulomb friction was pulled from 13 mN m down to 4; then a mis-read of the
  A/B decay moved it to 8. Both were wrong. The first ignored that the wheel does not rotate below
  ~5 mN m commanded, so the sweep had found the motor's cogging as much as the bearing's stiction.
  The second averaged a stretch of the decay where the platform was still being pushed by hand,
  giving 120 deg/s^2 where the arrest alone is 161. Re-fitting on the corrected number lands at
  12.3 mN m - within a few percent of the original value, from a single measurement and a prior.
  What caught it: `tools/overlay.py` ran the model and the rig through the same coast and they
  disagreed by 1.5x, which is not something a model fitted to that very run can do. **A plant
  model checked only against itself will absorb a bad measurement without complaining.** The
  overlay is now a scenario of its own (SIL-015) so the comparison runs with the suite.
- **2026-08-04** - **Breakaway torque measured: 5 mN m.** The vehicle pulsed its own wheel at
  rising torque over the radio with nothing plugged into it, and reported the peak body rate each
  pulse produced: 4 mN m moved it 0.1 deg/s, 5 mN m turned it at 7.5. The plant model had guessed
  16.3 - a factor of three - because a coast-down only ever sees sliding friction and the sticking
  case was 1.25x that, a ratio sitting on top of a fit. Re-fitting with both measurements
  separated the terms properly for the first time: the coast-down pins total drag at speed, the
  sweep pins the sticking case, and what is left has to be viscous.
  **SIL-011 promptly failed**, which is the harness doing its job. It had been nulling a 2 rad/s
  spin, and with three times less free drag the wheel ran 36.02 of 36 - it had been passing on
  borrowed friction. At 1.6 rad/s it peaks at 27.8, so the honest statement of this vehicle's
  authority moved from "a 2 rad/s upset" to "about 1.6 rad/s, 90 deg/s". A unit test that assumed
  10 mN m was below breakaway failed in the same pass, for the same reason.
- **2026-08-04** - Getting that measurement took two tries, and both failures were instructive.
  The first tool drove the ESC over USB - but the USB cable *is* the tether, and a cable across
  the rotating joint is a torsion spring, so it measured the cable. The second put the sweep on
  the radio but had the ground compare heading before and after each pulse: the platform's answer
  is a transient that starts and ends inside a second, and the radio carries one attitude frame a
  second, so a real 13 deg/s jolt was recorded as "no movement". The fix was to stop inferring -
  the vehicle now reports the peak rate it saw since its last pulse, watched at the control rate.
  Measure where the data is.
- **2026-08-04** - **POINTING works on the rig.** Commanded to a bearing 28 degrees away, on
  battery with nothing plugged in and everything over the radio, the platform converged
  monotonically - error -27.9, -21.8, -16.3, -12.5, -5.3, -2.0, -0.7 - and held at 0.7 degrees
  against a 2.9 degree band, with no overshoot. It gets there by inching: the feedforward breaks
  the bearing loose, the platform moves, the push drops out, friction stops it, repeat. That is
  the honest gait for a wheel this size on a bearing this stiff.
- **2026-08-04** - Getting there took two wrong turns worth keeping. The pointing law was a PD on
  angle whose gain saturated the wheel at 7 degrees of error, so it was a relay rather than a
  controller and the rig answered with 130 deg/s slams and 19 degrees of overshoot; it became a
  cascade, an outer loop asking for a bounded slew rate and an inner loop that is detumble's law
  with a setpoint. Then that inner loop was given a gain twelve times detumble's measured one, to
  give the slew enough torque to break stiction, and it oscillated at 215 deg/s - the same mistake
  as the morning's, larger. The answer was not a gain at all but a constant feedforward.
- **2026-08-04** - POINTING and DETUMBLE were fighting each other. A slew is body rate on purpose,
  and it passed the autonomous-detumble threshold long before reaching the target, so the vehicle
  cancelled its own manoeuvre, resumed, and started again - forty seconds of that without
  arriving. REQ-MODE-012 now excludes POINTING: detumble answers rate nobody asked for.
- **2026-08-04** - The magnetometer is held off while the flywheel turns. Its rotor magnets sweep
  the field past the sensor at eleven times shaft rate, far above the 10 Hz sample, and the
  heading walked ~5 deg/s with the gyro reporting the platform was still. The first version of the
  gate asked the ESC's velocity, which reads +/-3 rad/s at a standstill, so it never opened at
  all; it asks the wheel *angle* now, which sat on the same count indefinitely. Attitude telemetry
  went to every control cycle in the same pass - a 10 Hz loop cannot be judged from 1 Hz samples,
  and a whole detumble was falling between two lines.
- **2026-08-04** - The last bench inhibit is gone. With the ground station holding the command
  link, COMMAND_LINK_LOSS came off the list and the vehicle now runs its real fault responses -
  which promptly safed it five seconds into the first quiet run, correctly. The console holds the
  link itself now, on 1.3 s of quiet rather than a 2 s metronome: 2 s is a harmonic of the 1 s
  beacon, so every keepalive landed in the same deaf window and none of them arrived. That trap
  was already written down two lessons above, and it still got walked into.
- **2026-08-03** - **The wheel is back.** The replacement B-G431B-ESC1 flashed, aligned FOC, and
  reported all four health flags; 2 V on the q axis spun it to 14.7 rad/s. The first upload failed
  with `open failed` because `platformio.ini` still pinned the dead board's ST-Link serial - the
  pin exists so an upload cannot land on the Nucleo, and a board swap is exactly when it bites.
  Wired to the OBC on USART1 crossed, `ESC: up at 5334 ms, flags=0x0F`; the 8 s acquire window
  written for the ESC's cold FOC alignment covered it, so no dropout latched. `WHEEL_DROPOUT` came
  off the bench-inhibit list and the temporary rx diagnosis block came out with it, leaving
  COMMAND_LINK_LOSS as the only inhibit. The rig is hardware-complete for the first time.
- **2026-08-03** - The wheel's sign was measured rather than assumed: positive q-volts turns the
  platform counterclockwise seen from above, which against the compass convention (clockwise
  positive) makes `tau = +k_rate * omega` damping, as written. The header comment had claimed
  `tau = -k_rate * omega` - the opposite of the code, in the one place a sign error already cost a
  session - and was corrected. The platform swinging ~15-20 deg and then stopping while the
  flywheel kept spinning is the momentum-exchange signature: reaction torque exists only while the
  wheel's speed is changing, and the platform's own stiction absorbed the rest.
- **2026-08-02** - The ground station got its CAD: `ground_plate`, `ground_cover`, and a
  `ground_assembly` tying them to the protoboard and the vendor OLED model. `stack_assembly`
  became `satellite_assembly`, since there are two assemblies on the desk now. Fusion stamps a
  fresh timestamp into every export, so a byte compare calls all 46 parts changed every time;
  `tools/cad_sync.py` compares only the geometry, and this drop touched exactly five files.
- **2026-07-31** - The one-word mission ran on battery: `shoot` walked point, capture, downlink,
  and park by itself, 451 chunks at 95% first-pass delivery, two request rounds, and
  `image_0018.jpg` on disk in twelve seconds. The first over-the-air `poll POWER` closed
  REQ-TLM-006, and switching the vehicle off put LOST and the age of the silence on the ground
  station's screen instead of a confident ghost.
- **2026-07-31** - The heartbeat carries the bus voltage now: on battery it is a vital sign, and
  the ground station's status panel draws it as a battery gauge mapped to the working range
  (13.6 V "land now" to 16.8 V full). The same panel pass gave both screens fixed regions, and
  the big word finally tells the truth about a dead link - LOST plus the age of the last
  heartbeat, instead of confidently showing the last mode of a switched-off vehicle.
- **2026-07-31** - First battery boot: 16.75 V on the main bus through the new PTC fuse, radio
  telemetry with no bench supply. The same session found the bias trap it sprang: the gyro bias
  was learned from the first two seconds after power-on, and a boot that happened while the
  platform was being handled read a phantom 144 deg/s at rest forever - autonomous detumble
  latched on a spin that did not exist. Bias now locks only from a window that stayed quiet end
  to end. And the ground can now `poll` one frame of any telemetry kind over the beacon
  (REQ-TLM-006), since the full sensor stream can never ride the low-rate link.
- **2026-07-30** - The console grew a mission: `shoot [size] [bearing]` walks point, aim,
  capture, downlink, park as one command, advancing each step on telemetry evidence rather than
  on having sent something. The compass gained a spike gate and smoothing after bench headings
  repeated only to tens of degrees - min/max calibration never forgets, so one glitched sample
  had been corrupting the spans for the rest of the boot. README and roadmap caught up with the
  radio arc they predated.
- **2026-07-30** - **The untethered pass - phase 8's deliverable.** No data cable on the vehicle:
  commanded into POINTING over LoRa, captured, and downlinked over nRF24 to
  `captures/image_0017.jpg`, markers intact. First pass delivered 72%; two selective-repeat
  rounds (10 missing, then 1) finished it, which is the protocol doing exactly its job. The same
  log shows auto-detumble catching two hand spins and handing the vehicle back, and pointing
  holding its captured heading to a fraction of a degree at rest. Power was the bench supply -
  the battery waits on its fuse.
- **2026-07-30** - Selective repeat closed the loop on the bench: two 800x600 images arrived
  complete over the air, gaps named and refilled. The gyro moved to +-2000 dps after fast spins
  clipped at 1000 and the heading "lost track"; a compass disagreement past ~57 degrees now snaps
  the estimate instead of dragging it back. The display convention (clockwise for an observer
  looking down) enters at exactly one constant, and a commanded SET_HEADING now outlives mode
  changes rather than being forgotten on re-entering POINTING.
- **2026-07-30** - The bench falsified two of the day's guesses. The compass sign, hand-picked
  twice and wrong twice, is now measured: the firmware correlates the mag angle against the gyro
  during the calibration turn and locks whichever sign agrees. And selective repeat's requests
  never arrived because they were triggered by the vehicle's own 1 Hz status frame - phase-locked
  into its transmit window, eight for eight lost. Requests now run on the ground's clock at 1.3 s,
  so no alignment survives a round.
- **2026-07-30** - DETUMBLE became autonomous protection: any operating mode that starts spinning
  pulls itself into the recovery and resumes where it was (REQ-MODE-012, SIL-014). The operating
  modes became a clique - the sequencing ladder encoded a deployment story the rig does not have.
  The compass gained live hard-iron calibration after the first bench run showed its field circle
  centred at +300 counts; it needs one full turn of the platform after power-up before it speaks.
- **2026-07-30** - The design audit's structural items landed. Heading became absolute: a
  complementary filter blends the gyro integral with a magnetometer compass heading, running in
  every mode, so the dial tracks the platform even in STANDBY and SET_HEADING names a repeatable
  bearing. DETUMBLE exits itself to STANDBY after a second inside the deadband (REQ-MODE-011,
  SIL-013). The executive's three retreat clauses collapsed into a fallback table.
- **2026-07-30** - The yaw axis is the IMU's X, not its Z: a bench spin swung gyro x by +/-10000
  counts while z saw tens of cross-coupling - the board is mounted x-vertical, and the control
  path had been watching the wrong channel since the plate was built. Bias is now learned from
  the first two seconds at rest, which was worth a quarter degree of heading every ten seconds.
- **2026-07-30** - The downlink became a protocol. Blind three-pass repetition replaced with
  selective repeat: one pass, then the ground names its missing chunks over the LoRa uplink and
  the vehicle resends exactly those out of the fifo it never consumed. Same audit fixed the
  pointing error not wrapping (a 216-degree command drove the long way round), made DETUMBLE
  commandable from both active modes, and stopped the console mangling what it echoes.
- **2026-07-30** - **First image down over the air**: 800x600 commanded over LoRa, 398 chunks over
  the nRF24, 22240 bytes reassembled with intact markers at 96% packet delivery. Three passes over
  the same frame is what closed it.
- **2026-07-30** - Payload link fixed and images reaching the ground station. Minimum transmit
  power took delivery from 39% to 88%: two PA+LNA modules a foot apart were overloading the
  receiver's front end, not struggling to reach it. 88% still delivers no image, because a frame
  spans three packets and an image needs every frame - so a downlink now makes three passes over
  the same frame, rewinding the ArduChip's read pointer rather than recapturing.
- **2026-07-30** - `CAPTURE_IMAGE` takes a size (320x240, 800x600, 1600x1200), `SET_HEADING` aims
  POINTING at a bearing, and `attitude_status_t` feeds a dial on the second panel. The payload
  radio dropped to minimum transmit power: two PA+LNA modules a foot apart delivered 224 of 570
  packets at full output, which is an overloaded receiver rather than a weak link.
- **2026-07-30** - Payload link proven, and the first real numbers off it. Strapping the second
  OLED to 0x3D exposed that `Adafruit_SSD1306::begin` reports a panel on an address with nothing
  on it, so the bus is probed directly now. With the link up, an image downlink put 588 packets on
  the air and 379 arrived - and only one frame decoded, because a frame spans three packets and
  the losses come in runs. The transmitter is paced from here.
- **2026-07-30** - The vehicle was transmitting the whole time. A downlink progress frame on the
  LoRa beacon reported 186/186 chunks and 549 nRF24 packets while the ground received nothing, so
  the failure is the ground station's receiver and never was the satellite. The ground station now
  emits its own health once a second rather than once at boot, which is what hid this: a receiver
  that failed to initialise printed one line before anybody had opened a terminal, and afterwards
  looked exactly like a working one hearing nothing. Beacon queue went to three deep in the same
  change - a heartbeat landing on a pending command ack was evicting it.
- **2026-07-30** - Documentation cut roughly in half and two link bugs fixed. The ground station
  was forwarding padding plus truncated frames on the payload link, which is why no image ever
  arrived; it now re-encodes each decoded frame. `rfm95_send` waits for its own transmit to finish
  instead of leaving the radio in standby until something polled, and the ground console
  retransmits an unacknowledged command, which the flight software makes safe by answering a
  repeated sequence number with the previous verdict rather than acting twice (REQ-CMD-003).
- **2026-07-30** - Link runs both ways. Beacon and command acks on LoRa, payload chunks on nRF24,
  commands up from the ground console into the same uplink task that decodes them from a uart. The
  ground station is a Feather M0 RFM95 compiling `common/protocol/` rather than reimplementing it,
  with an SSD1306 showing mode, faults and link with no PC attached. **Owed: the untethered run.**
- **2026-07-30** - Legacy sweep. Radio health telemetry filled the `LoraStatus`/`Nrf24Status` ids
  reserved since June; SPI arbitration moved to a per-peripheral lock; CubeIDE project files and
  the ESC probe env removed; the PAL boundary became an automated check (REQ-PAL-001).
- **2026-07-30** - Requirement backlog cleared: REQ-WDG-002 and REQ-TLM-005 bench-verified,
  REQ-SNS-003 deferred as conditional on redundancy this build does not have.
- **2026-07-30** - Camera dropout test (REQ-PAY-002), which produced the ground-reference finding
  above. Fault bead confirmed orange with a Degraded and a Warning fault latched together.

### Phase 7 - ADCS

- **2026-07-30** - Plant model, closed SIL loop, detumble and pointing laws. SIL-011 nulls a
  2 rad/s spin inside the deadband; SIL-012 shows a sustained disturbance saturating the wheel.
  Inertias measured from Fusion (j_wheel 1.09e-4, j_platform 4.53e-3 kg m^2); friction fitted to a
  hand-timed coast-down, ~6.28 rad/s to rest in ~2 s. **REQ-ADCS-002 deliberately not claimed:**
  at 10 Hz with rate-only sensing a 0.35 rad/s shove moved the platform 0.117 rad while the gyro
  read zero at every sample. A sensing limit, not a control limit.
- **2026-07-30** - NASA 42 evaluated and set aside; reasoning in `roadmap.md` under Simulation.

### Phase 6 - real-time task model

- **2026-07-30** - Telemetry and payload downlink became their own tasks, and
  `kPayloadChunksPerCycle` was deleted as a link fact that had leaked across the PAL. A 6117-byte
  frame went from ~3 s to ~1 s. The same run exposed a latent watchdog reset: the downlink task
  reported liveness once per image rather than once per chunk, which on a full-resolution frame
  would have reset the board mid-contact.
- **2026-07-30** - Uplink moved off the control task; the project's first `FromISR` call. Fault
  inhibits reached the wire, and an undervoltage sweep closed REQ-FAULT-002, REQ-FAULT-001,
  REQ-MODE-006 and REQ-HMI-001 in one run - latched at 13.6 V, SAFE within one heartbeat, no
  autonomous climb out, recovery a deliberate two-step by ground command.
- **2026-07-29** - Phase 6 closed. HIL-003 passed 7/7: watchdog fed in all 60 reports, worst stack
  margin 104 words against a 64 floor, 59 heartbeat periods at a 1.000 s mean. The bite was
  demonstrated separately (`reset=iwdg-watchdog`). Stacks sized against measured peaks.

### Phase 5 - sensors and payload

- **2026-07-29** - The whole payload arc on real silicon: commanded capture in POINTING, then 121
  chunks in DOWNLINK reassembled to a 6759-byte jpeg with markers intact at both ends.
- **2026-07-28** - Every mode commanded on hardware. BOOT was a dead end - nothing ever requested
  BOOT -> STANDBY - which the mode ladder test found (REQ-MODE-010).
- **2026-07-27** - Camera produced a real 7688-byte jpeg. The ArduChip's length register is **not**
  the image size: two captures of different scenes both reported 7688 while the jpeg inside
  differed by ~100 bytes, so the driver scans for FF D9 rather than trusting it.
- **2026-07-26** - Satellite hardware build complete, all three plates. WS2812s need 5 V; a 3.3 V
  supply is below their minimum and they simply do not light.
- **2026-07-21** - Gimbal plate complete: closed-loop FOC on a verified AS5600 encoder, and the
  reaction-wheel effect demonstrated at up to ~344 RPM.

### Phases 0-4 - foundation

- **2026-06-11** - Phase 4 complete. Both HIL scenarios passed on the live board, with the flight
  software running unmodified on the STM32 behind the PAL.
- **2026-06-10** - Phase 3 complete: the scenario runner. Phase 2's executive and comms before it.
- **2026-06-09** - The wire contract settled at `common/protocol/` in C++, so the ground firmware
  could be a genuine second consumer rather than a copy.
- **2026-06-07** - Dual-link comms decided: an always-on LoRa TT&C beacon plus an nRF24 payload
  downlink active only in DOWNLINK. That split is what makes DOWNLINK a real mode.
- **2026-06-06** - Requirements-first pass; hardware standard finalised and ordered.

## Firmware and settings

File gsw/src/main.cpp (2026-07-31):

/**
 * @file   main.cpp
 * @brief  ground station - hears the vehicle on two radios and pumps it out usb serial
 *
 * The whole job is to be a frame pipe. A packet arrives over the air, whole frames are recovered
 * from it and written to the usb port, and `tools/uart_monitor.py` decodes them with the same
 * FrameDecoder it already uses on the st-link cable - because the frame format does not change per
 * transport, which is the point REQ-TLM-004 exists to make.
 *
 * Frames rather than bytes, because the two radios do not deliver a clean byte stream: nRF24
 * packets carry padding and LoRa packets arrive between them. Decoding per radio and re-encoding
 * on the way out gives the pc exactly what the satellite emitted, from both links, on one port.
 *
 * The display reads the heartbeats going past, using the satellite's own catalogs (display.cpp).
 *
 * Uplink works the same way in reverse: whatever the pc types arrives here as encoded command
 * frames on usb, and they go out over lora unexamined. `uart_monitor.py` builds them exactly as
 * it does for the wired console, so commanding over the air needed no ground-tool change at all.
 */

#include <Arduino.h>

#include "display.hpp"
#include "protocol/frame.hpp"
#include "protocol/msg.hpp"
#include "protocol/state.hpp"
#include "radios.hpp"

namespace {

constexpr uint8_t kPinLed = 13;

// the led says which of three things is true, because a board that is fine and a board that is
// dead look identical when the only signal is "off". fast blink is init failure; a brief flash
// every 2 s is alive but hearing nothing; a longer flash is a frame that passed crc
constexpr uint32_t kAliveBlinkMs = 2000;
constexpr uint32_t kAliveFlashMs = 20;
constexpr uint32_t kFrameFlashMs = 60;

// how long after the last payload packet the screen keeps its hands off the bus
constexpr uint32_t kDownlinkQuietMs = 500;

uint32_t led_off_at = 0;
uint32_t next_alive_blink = 0;

bool lora_up = false;
bool nrf_up = false;

// one parser PER RADIO. sharing them was a real bug: a heartbeat arriving over lora between two
// nrf24 payload packets spliced itself into the middle of an image frame, and the interleaved
// bytes went out usb in that order too, so the pc saw the same wreckage
struct link_t {
    fsw::frame_parser_t parser;
    uint32_t frames;  // whole crc-checked frames recovered on this link since boot
};

link_t lora_link{};
link_t nrf_link{};

// how often the ground station says how it is doing. it used to say so once, at boot, and a
// receiver that failed to initialise then was indistinguishable from a working one hearing
// nothing - which is exactly what hid a dead payload radio while the vehicle transmitted a whole
// image into it. once a second, forever, so it is true whenever somebody opens a terminal
constexpr uint32_t kGroundStatusMs = 1000;
uint32_t next_status_ms = 0;

fsw::frame_parser_t up_parser;  // uplink, from usb - re-encoded on the way out, same as the rx side

// when the payload link last delivered anything, so the screen can stay out of its way
uint32_t last_nrf_ms = 0;

// whether the vehicle says it is in DOWNLINK, read off the heartbeat
bool vehicle_downlinking = false;

void led_flash(uint32_t ms) {
    digitalWrite(kPinLed, HIGH);
    led_off_at = millis() + ms;
}

void led_service() {
    const uint32_t now = millis();
    if (led_off_at != 0 && static_cast<int32_t>(now - led_off_at) >= 0) {
        digitalWrite(kPinLed, LOW);
        led_off_at = 0;
    }
    if (led_off_at == 0 && static_cast<int32_t>(now - next_alive_blink) >= 0) {
        next_alive_blink = now + kAliveBlinkMs;
        led_flash(kAliveFlashMs);
    }
}

// decode one link's bytes, and re-encode every whole frame onto usb.
//
// re-encoding rather than forwarding the received bytes is the point. the obvious version keeps a
// shadow copy of what arrived and writes that when the parser says a frame ended - and it does not
// work, because the bytes on the air are not only frame bytes. the nrf24 pads every packet to 32,
// a payload frame is 70, so each frame arrives as three packets carrying 70 frame bytes and 26
// zeros. those zeros land in the shadow buffer, the next frame overruns it, and what goes to the
// pc is padding followed by a truncated frame. every image frame failed crc at the pc for this
// reason and nothing was ever reassembled.
//
// the parser already found the frame boundaries and checked the crc. frame_encode is deterministic,
// so re-encoding gives back exactly the bytes the satellite emitted, with no padding and no way for
// two radios to interleave mid-frame
void on_link_rx(link_t& link, const uint8_t* data, size_t len) {
    for (size_t i = 0; i < len; i++) {
        auto f = fsw::frame_decode(&link.parser, data[i]);
        if (!f) {
            continue;
        }

        uint8_t out[fsw::kFrameMaxSize];
        const size_t n = fsw::frame_encode(f->msg_id, f->payload, f->len, out);
        Serial.write(out, n);
        link.frames++;

        led_flash(kFrameFlashMs);
        next_alive_blink = millis() + kAliveBlinkMs;  // do not stack an alive blink on top

        if (f->msg_id == static_cast<uint8_t>(fsw::MsgId::Heartbeat) &&
            f->len == sizeof(fsw::heartbeat_t)) {
            fsw::heartbeat_t hb{};
            memcpy(&hb, f->payload, sizeof(hb));
            // knowing the mode is what lets the screens stay off the bus for a whole pass rather
            // than only between packets - see the gate in loop()
            vehicle_downlinking = (hb.mode == static_cast<uint8_t>(fsw::Mode::DOWNLINK));
            display_heartbeat(hb);
        } else if (f->msg_id == static_cast<uint8_t>(fsw::MsgId::AttitudeStatus) &&
                   f->len == sizeof(fsw::attitude_status_t)) {
            fsw::attitude_status_t a{};
            memcpy(&a, f->payload, sizeof(a));
            display_attitude(a);
        } else if (f->msg_id == static_cast<uint8_t>(fsw::MsgId::DownlinkStatus) &&
                   f->len == sizeof(fsw::downlink_status_t)) {
            fsw::downlink_status_t d{};
            memcpy(&d, f->payload, sizeof(d));
            display_downlink(d);
        }
    }
}

void on_lora_rx(const uint8_t* data, size_t len) { on_link_rx(lora_link, data, len); }

void on_nrf_rx(const uint8_t* data, size_t len) {
    last_nrf_ms = millis();
    on_link_rx(nrf_link, data, len);
}

// take whatever the pc sent and put whole frames on the air. anything that is not a frame is
// dropped rather than transmitted - the decoder is the judge of what counts
void service_uplink() {
    while (Serial.available() > 0) {
        const int b = Serial.read();
        if (b < 0) {
            return;
        }

        auto f = fsw::frame_decode(&up_parser, static_cast<uint8_t>(b));
        if (!f) {
            continue;
        }

        uint8_t out[fsw::kFrameMaxSize];
        const size_t n = fsw::frame_encode(f->msg_id, f->payload, f->len, out);
        lora_send(out, n);
    }
}

// the ground station's own health, as a frame like everything else - so the console decodes it
// with the decoder it already has rather than parsing a line of text
void service_ground_status() {
    const uint32_t now = millis();
    if (static_cast<int32_t>(now - next_status_ms) < 0) {
        return;
    }
    next_status_ms = now + kGroundStatusMs;

    fsw::ground_status_t g{};
    g.t_ms = now;
    g.lora_frames = lora_link.frames;
    g.nrf24_frames = nrf_link.frames;
    g.nrf24_packets = nrf24_packets();
    g.nrf24_busy_pct = nrf_up ? nrf24_channel_busy_pct() : 0U;
    g.flags = static_cast<uint8_t>((lora_up ? fsw::kGroundFlagLoraUp : 0U) |
                                   (nrf_up ? fsw::kGroundFlagNrf24Up : 0U) |
                                   (display_have_status_panel() ? fsw::kGroundFlagPanel1 : 0U) |
                                   (display_have_payload_panel() ? fsw::kGroundFlagPanel2 : 0U));

    uint8_t out[fsw::kFrameMaxSize];
    const size_t n = fsw::frame_encode(static_cast<uint8_t>(fsw::MsgId::GroundStatus),
                                       reinterpret_cast<const uint8_t*>(&g), sizeof(g), out);
    Serial.write(out, n);
}

}  // namespace

void setup() {
    pinMode(kPinLed, OUTPUT);
    digitalWrite(kPinLed, LOW);

    Serial.begin(115200);
    // deliberately not waiting for a host - a ground station that hangs until someone opens a
    // terminal is a ground station that looks dead when it is fine

    // the display first, so a radio that fails to come up has somewhere to say so
    display_begin();

    lora_up = lora_begin();
    nrf_up = nrf24_begin();

    if (!lora_up || !nrf_up) {
        // the only text this ever prints, and it cannot be mistaken for telemetry: a frame starts
        // AA 55 and the decoder resyncs past anything else
        Serial.print("GSW: init failed -");
        if (!lora_up) {
            Serial.print(" lora");
        }
        if (!nrf_up) {
            Serial.print(" nrf24");
        }
        Serial.println(" - check cs wiring and the 3v3 rail");
    }

    // a radio that never came up is a hard stop only if BOTH are down - one working link is still
    // a ground station, and saying which one failed is more useful than refusing to run
    if (!lora_up && !nrf_up) {
        while (true) {
            digitalWrite(kPinLed, HIGH);
            delay(100);
            digitalWrite(kPinLed, LOW);
            delay(100);
            display_service(display_counts_t{0, 0, 0, 0, false, false, false});
        }
    }
}

void loop() {
    if (lora_up) {
        lora_poll(on_lora_rx);
    }
    if (nrf_up) {
        nrf24_poll(on_nrf_rx);
    }
    if (lora_up) {
        service_uplink();
    }
    led_service();

    // deliberately outside the downlink-quiet gate below: the whole point of this frame is to be
    // heard during a downlink that is going wrong, and it is 23 bytes over usb rather than 25 ms
    // on the i2c bus
    service_ground_status();

    // a redraw is ~25 ms of blocking i2c per panel, and with two panels that is 50 ms during which
    // nothing drains a three-deep radio fifo. so the screens are told when the payload link is
    // busy and slow themselves down to one panel once a second, rather than being skipped.
    //
    // two earlier versions of this were wrong in opposite directions. gating on "is a packet
    // waiting right now" lost a burst that began just after a draw started - one pass delivered
    // 88% and the next 33%. gating on the vehicle's mode instead skipped every redraw for the
    // whole pass, so the progress bar existed and was never drawn. this runs immediately after
    // nrf24_poll has emptied the fifo, which is the safest moment a draw can start, and the rate
    // limit inside display_service is what bounds the cost to about 2.5% of a pass
    const bool busy =
        nrf_up && (vehicle_downlinking || (millis() - last_nrf_ms) < kDownlinkQuietMs);

    const display_counts_t counts{
        lora_packets(), nrf24_packets(), lora_link.frames, nrf_link.frames, lora_up, nrf_up, busy};
    display_service(counts);
}

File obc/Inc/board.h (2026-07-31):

/**
 * @file   board.h
 * @brief  NUCLEO-F446RE pin map - the one place board wiring lives
 *
 * Each signal's port/pin/af (alternate function)
 */
#ifndef BOARD_H
#define BOARD_H

#include "stm32f446xx.h"

// interrupt priority plan. cortex-m priorities are least-urgent-when-numerically-largest, and
// freertos refuses a FromISR call from any isr more urgent than
// configLIBRARY_MAX_SYSCALL_INTERRUPT_PRIORITY (5) - it trips configASSERT. everything here that
// talks to the kernel sits at or above that number; 6 leaves 5 free for something that has to be
// more urgent than the uarts and still hand work to a queue
#define IRQ_PRIO_UART 6U

// status led - ld2
#define LD2_PORT GPIOA
#define LD2_PIN  5U

// ws2812 status array - single-wire data on pa8, clocked out by tim1_ch1 (af1) + dma2
#define WS2812_PORT   GPIOA
#define WS2812_PIN    8U
#define WS2812_AF     1U
#define WS2812_TIM    TIM1
#define WS2812_DMA    DMA2
#define WS2812_STREAM DMA2_Stream1
#define WS2812_DMA_CH 6U  // stream 1 channel 6 = tim1_ch1
#define WS2812_COUNT  3U  // 3 beads

// imu - spi2 (sck/miso/mosi af5, cs driven as a plain gpio)
#define IMU_SPI      SPI2
#define IMU_SPI_PORT GPIOB
#define IMU_SCK_PIN  13U
#define IMU_MISO_PIN 14U
#define IMU_MOSI_PIN 15U
#define IMU_SPI_AF   5U
#define IMU_CS_PORT  GPIOB
#define IMU_CS_PIN   12U

// sensors - i2c1 (scl/sda af4) - ina228 + tmp117 share the bus
#define SENSOR_I2C      I2C1
#define SENSOR_I2C_PORT GPIOB
#define I2C_SCL_PIN     8U
#define I2C_SDA_PIN     9U
#define I2C_AF          4U

// actuation - usart1 (tx/rx af7) - stm32g431cb esc
#define ESC_UART   USART1
#define ESC_PORT   GPIOA
#define ESC_TX_PIN 9U
#define ESC_RX_PIN 10U
#define ESC_AF     7U
#define ESC_IRQ    USART1_IRQn

// console - usart2 (af7) -> st-link vcp over usb
#define CONSOLE_UART   USART2
#define CONSOLE_PORT   GPIOA
#define CONSOLE_TX_PIN 2U
#define CONSOLE_RX_PIN 3U
#define CONSOLE_AF     7U
#define CONSOLE_IRQ    USART2_IRQn

// downlink - usart6 (af8) -> header link
#define DOWNLINK_UART   USART6
#define DOWNLINK_PORT   GPIOC
#define DOWNLINK_TX_PIN 6U
#define DOWNLINK_RX_PIN 7U
#define DOWNLINK_AF     8U
#define DOWNLINK_IRQ    USART6_IRQn

// camera - spi3 (sck/miso/mosi af6, cs on pb0 as a plain gpio) - arducam ov2640 fifo
#define CAMERA_SPI      SPI3
#define CAMERA_SPI_PORT GPIOC
#define CAMERA_SCK_PIN  10U
#define CAMERA_MISO_PIN 11U
#define CAMERA_MOSI_PIN 12U
#define CAMERA_SPI_AF   6U
#define CAMERA_CS_PORT  GPIOB
#define CAMERA_CS_PIN   0U

// lora - rfm95 on the same spi3 wires as the camera, its own cs plus two control lines.
// the bus pins are deliberately not repeated: they are the CAMERA_* ones above, because there is
// one spi3 and three devices hanging off it (wiring.md, "the SPI3 bus as single nodes")
#define LORA_CS_PORT   GPIOB
#define LORA_CS_PIN    7U  // cn7-21
#define LORA_RST_PORT  GPIOA
#define LORA_RST_PIN   1U  // cn7-30
#define LORA_DIO0_PORT GPIOA
#define LORA_DIO0_PIN  0U  // cn7-28, tx-done / rx-done - polled for now, interrupt later

// nrf24l01+ - the third device on spi3, the high-rate payload path. csn is the chip select; ce
// gates the radio itself and is held high so the fifo drains without a timed pulse
#define NRF24_CSN_PORT GPIOA
#define NRF24_CSN_PIN  4U  // cn7-32
#define NRF24_CE_PORT  GPIOC
#define NRF24_CE_PIN   2U  // cn7-35
#define NRF24_IRQ_PORT GPIOC
#define NRF24_IRQ_PIN  3U  // cn7-37, unused while the driver polls

#endif  // BOARD_H

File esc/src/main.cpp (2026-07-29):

/**
 * @file   main.cpp
 * @brief  reaction-wheel node - b-g431b-esc1 (stm32g431) running simplefoc in torque mode
 *
 * speaks the same framed, crc-checked protocol as the rest of the system (common/protocol),
 * so the obc link is not a second wire format to maintain. usart2 on pb3/pb4 reaches both
 * the onboard st-link vcp and the j3 header the obc harness lands on (um2516 table 4 - the
 * only usart brought out), so pull the usb cable when the obc is driving.
 */

#include <SimpleFOC.h>

#include "protocol/frame.hpp"
#include "protocol/msg.hpp"

HardwareSerial SerialLink(PB4, PB3);

#define SERIAL_BAUD        115200
#define COMMAND_TIMEOUT_MS 500  // no command for this long -> coast
#define STATUS_PERIOD_MS   250

BLDCMotor motor = BLDCMotor(11);  // 11 pole pairs, confirmed
BLDCDriver6PWM driver =
    BLDCDriver6PWM(A_PHASE_UH, A_PHASE_UL, A_PHASE_VH, A_PHASE_VL, A_PHASE_WH, A_PHASE_WL);
MagneticSensorI2C sensor = MagneticSensorI2C(AS5600_I2C);

static float target_voltage = 0.0f;  // uq in volts - starts at zero, nothing spins uncommanded
static uint32_t last_command_ms = 0;
static uint16_t last_seq = 0;
static bool foc_ready = false;
static bool sensor_ok = false;
static bool magnet_ok = false;
static bool driver_ok = false;

#define AS5600_ADDR       0x36
#define AS5600_STATUS_REG 0x0B
#define AS5600_MD_BIT     0x20  // magnet detected

// an address ack only proves the chip is alive - MD is what says it can see the magnet
static bool as5600_magnet_detected() {
    Wire.beginTransmission(AS5600_ADDR);
    Wire.write(AS5600_STATUS_REG);
    if (Wire.endTransmission(false) != 0) {
        return false;
    }
    if (Wire.requestFrom((uint8_t)AS5600_ADDR, (uint8_t)1) != 1) {
        return false;
    }
    return (Wire.read() & AS5600_MD_BIT) != 0;
}

static fsw::frame_parser_t parser;

static void send_status() {
    fsw::wheel_status_t s{};
    s.velocity_mrad_s = (int32_t)(motor.shaft_velocity * 1000.0f);
    s.angle_mrad = (int32_t)(sensor.getAngle() * 1000.0f);  // raw sensor - true either way
    s.torque_mv = (int16_t)(target_voltage * 1000.0f);
    s.flags =
        (foc_ready ? fsw::kWheelFlagFocReady : 0U) | (sensor_ok ? fsw::kWheelFlagSensorOk : 0U) |
        (magnet_ok ? fsw::kWheelFlagMagnetOk : 0U) | (driver_ok ? fsw::kWheelFlagDriverOk : 0U);
    s.seq = last_seq;

    uint8_t buf[fsw::kFrameMaxSize];
    const size_t n =
        fsw::frame_encode((uint8_t)fsw::MsgId::WheelStatus, (const uint8_t*)&s, sizeof(s), buf);
    SerialLink.write(buf, n);
}

static void apply(const fsw::frame_t& f) {
    if (f.msg_id != (uint8_t)fsw::MsgId::WheelCommand || f.len != sizeof(fsw::wheel_command_t)) {
        return;
    }

    fsw::wheel_command_t c{};
    memcpy(&c, f.payload, sizeof(c));

    float v = (float)c.torque_mv / 1000.0f;
    if (v > motor.voltage_limit) {
        v = motor.voltage_limit;  // the obc does not get to exceed the local ceiling
    } else if (v < -motor.voltage_limit) {
        v = -motor.voltage_limit;
    }

    target_voltage = v;
    last_seq = c.seq;
    last_command_ms = millis();
    send_status();  // every command gets an answer
}

void setup() {
    SerialLink.begin(SERIAL_BAUD);
    delay(1000);

    Wire.setSDA(PB7);
    Wire.setSCL(PB8);
    Wire.begin();

    // address-only probe before anything reads registers - separates a missing encoder
    // from a failed alignment, which look identical from the obc otherwise
    Wire.beginTransmission(AS5600_ADDR);
    sensor_ok = (Wire.endTransmission() == 0);
    magnet_ok = as5600_magnet_detected();

    sensor.init(&Wire);
    motor.linkSensor(&sensor);

    driver.voltage_power_supply = 14.8f;
    driver.voltage_limit = 10.0f;  // hard ceiling
    driver_ok =
        (driver.init() != 0);  // no pwm at all if this fails, which looks like a dead bridge
    motor.linkDriver(&driver);

    // torque (voltage) mode - no pid in the loop
    motor.torque_controller = TorqueControlType::voltage;
    motor.controller = MotionControlType::torque;
    motor.voltage_limit = 8.0f;
    motor.voltage_sensor_align = 6.0f;  // 4.0 was marginal once the flywheel went on

    motor.init();
    foc_ready = (motor.initFOC() != 0);  // reported in the status flags, not assumed

    last_command_ms = millis();
}

void loop() {
    if (foc_ready) {
        motor.loopFOC();
        motor.move(target_voltage);
    } else {
        sensor.update();  // keep the angle live so the encoder can still be checked by hand
    }

    while (SerialLink.available() > 0) {
        auto f = fsw::frame_decode(&parser, (uint8_t)SerialLink.read());
        if (f) {
            apply(*f);
        }
    }

    // dead-man: a hung obc or a pulled cable must not leave the wheel spinning
    if (target_voltage != 0.0f && (millis() - last_command_ms) > COMMAND_TIMEOUT_MS) {
        target_voltage = 0.0f;
        send_status();
    }

    static uint32_t t_last = 0;
    if (millis() - t_last > STATUS_PERIOD_MS) {
        t_last = millis();
        send_status();
    }
}

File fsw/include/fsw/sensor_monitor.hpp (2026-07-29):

/**
 * @file   sensor_monitor.hpp
 * @brief  turns sensor readings into fault samples for the fault manager (the detect step)
 */

#ifndef FSW_SENSOR_MONITOR_HPP
#define FSW_SENSOR_MONITOR_HPP

#include <cstdint>
#include <optional>

#include "fsw/fault_manager.hpp"
#include "fsw/inputs.hpp"
#include "protocol/msg.hpp"

namespace fsw {

// converts raw sensor readings into per-fault good/bad samples and feeds the fault manager
class SensorMonitor {
   public:
    /**
     * @brief  judge all of this cycle's sensor readings and update their dropout faults
     * @param  inputs this cycle's inputs (the sensor samples it carries)
     * @param  fm     fault manager to feed (it debounces and latches)
     * @param  t_ms   platform time (ms since boot)
     */
    void evaluate(const Inputs& inputs, FaultManager& fm, uint32_t t_ms);

   private:
    // one detector per sensor, called by evaluate(); a nullopt sample is no opinion (REQ-SNS-002)

    /**
     * @brief  evaluate imu data and update necessary faults
     * @param  imu    imu data sample
     * @param  fm     fault manager to feed
     * @param  t_ms   platform time
     */
    void evaluate_imu(const std::optional<imu_data_t>& imu, FaultManager& fm, uint32_t t_ms);

    /**
     * @brief  evaluate power data and update necessary faults
     * @param  power  power data sample
     * @param  fm     fault manager to feed
     * @param  t_ms   platform time
     */
    void evaluate_power(const std::optional<power_data_t>& power, FaultManager& fm, uint32_t t_ms);

    /**
     * @brief  evaluate temperature data and update necessary faults
     * @param  temp   temperature data sample
     * @param  fm     fault manager to feed
     * @param  t_ms   platform time
     */
    void evaluate_temp(const std::optional<temp_data_t>& temp, FaultManager& fm, uint32_t t_ms);

    /**
     * @brief  judge the wheel link's silence and update WHEEL_DROPOUT
     * @param  wheel  wheel status, set only on the cycles one arrived
     * @param  fm     fault manager to feed
     * @param  t_ms   platform time
     */
    void evaluate_wheel(const std::optional<wheel_status_t>& wheel, FaultManager& fm,
                        uint32_t t_ms);

    /**
     * @brief  evaluate payload camera health and update CAMERA_DROPOUT
     * @param  camera camera health sample
     * @param  fm     fault manager to feed
     * @param  t_ms   platform time
     */
    void evaluate_camera(const std::optional<camera_data_t>& camera, FaultManager& fm,
                         uint32_t t_ms);

    // last reading per source and when it last changed
    // imu
    int16_t prev_accel_[3] = {};
    int16_t prev_gyro_[3] = {};
    int16_t prev_mag_[3] = {};
    uint32_t accel_changed_ms_ = 0;
    uint32_t gyro_changed_ms_ = 0;
    uint32_t mag_changed_ms_ = 0;
    // wheel link - when the esc last answered, and whether it ever has (the first frame gets a
    // longer window, since the esc aligns foc before it can talk)
    uint32_t wheel_seen_ms_ = 0;
    bool wheel_acquired_ = false;
};

}  // namespace fsw

#endif  // FSW_SENSOR_MONITOR_HPP

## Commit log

2026-06-04 docs: add project overview, architecture, setup, and bill of materials
2026-06-04 feat(firmware): add bare-metal LED blink on STM32F446RE
2026-06-04 build: run just recipes in powershell on windows
2026-06-05 feat(firmware): add clock and gpio drivers
2026-06-05 feat(firmware): add interrupt-driven usart2 driver
2026-06-05 feat(firmware): add frame and message protocol
2026-06-05 feat(firmware): stream telemetry heartbeat over uart
2026-06-05 docs: mark bare-metal uart telemetry working on bench
2026-06-05 refactor(tools): extract the frame codec into frames.py
2026-06-05 test(tools): add frame codec tests and run them in CI
2026-06-05 refactor(protocol): move the frame/msg code into common/
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2026-06-07 docs(bom): drop the unused CAN parts and the oscilloscope
2026-06-10 refactor(bsp): drop the debug telemetry app - the drivers just move bytes
2026-06-10 fix(bsp): sleep in the uart tx spin and assert the ring size
    [uart.c]
2026-06-10 refactor(protocol): rewrite the wire contract in C++ at common/protocol
2026-06-10 refactor(tools): sync the python codec with the new wire contract
2026-06-10 feat(fsw): add command validation and the command-loss timer
2026-06-11 feat(tools): add ack decoding to the frames codec
2026-06-11 feat(bsp): run the flight software on the stm32
2026-06-11 refactor(tools): extract a shared ground package and runner core
2026-06-12 ci: exclude the stm32 backend from host clang-tidy
2026-06-12 feat(tools): echo firmware debug text through the uart monitor
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2026-06-12 feat(bsp): bring up the icm-20948 imu with a live accel/gyro readout
2026-06-12 docs: add the icm-20948 to the bom and note the live sensor bring-up
2026-06-12 docs(bom): correct the imu bus wording and fix a dead datasheet link
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2026-06-13 feat(bsp): read the ak09916 magnetometer over the imu's i2c master
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2026-06-15 refactor(bsp): rework the spi driver api and bake its speed
    [spi.c]
2026-06-15 refactor(bsp): bake the uart baud and return errors by value
    [uart.c]
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2026-06-15 docs: sync to the driver reorg and fault model
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2026-06-18 fix(i2c): reset the f4's wedged STOP before each transfer
    [i2c.c]
2026-06-18 feat(fault): add POWER_DROPOUT and retire the temperature faults
2026-06-18 docs: mark the INA228 power monitor working on the bench
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2026-06-19 feat(temp): add the TMP117 temperature sensor end to end
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2026-06-25 feat(cad): init cad library (parts, vendor refs, assemblies)
    [AS5600_v3.f3d, Arducam MINI OV2640_v1.f3d, CON-SMA-EDGE-S--3DModel-STEP-269445_v1.f3d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]
2026-06-25 feat(bsp): catch hardfaults, dump the context, and reboot
    [fault.c]
2026-06-25 feat(bsp): report reset cause in the boot banner
    [main.cpp]
2026-06-26 feat(cad): cad updates
    [AS5600_v3.f3d, Arducam MINI OV2640_v1.f3d, CON-SMA-EDGE-S--3DModel-STEP-269445_v1.f3d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]
2026-06-26 feat(cad): first gimbal + compute assembly
    [AS5600_v3.f3d, CON-SMA-EDGE-S--3DModel-STEP-269445_v1.f3d, GM4108H-120T_v31.f3d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]
2026-07-20 feat(cad): first full stack assembly
    [AS5600_v3.f3d, AS5600_v4.step, CON-SMA-EDGE-S--3DModel-STEP-269445_v1.f3d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]
2026-07-20 feat(cad): comms plate fixes
    [buck_cover_v12.step, comms_assembly_v17.step, comms_assembly_v18.step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]
2026-07-27 feat(cad): final for sure this time
    [AS5600_v4.step, CON-SMA-EDGE-S--3DModel-STEP-269445_v1.step, GM4108H-120T_v31.step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]
2026-07-28 docs: sync to the assembled rig and vendor the remaining datasheets
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2026-07-29 feat(obc): add ov2640 camera driver with vendored register tables
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2026-07-29 feat(fsw): add wheel and camera dropout faults with response inhibits
2026-07-29 feat(obc): wire the camera, uplink, and payload downlink into the node
2026-07-29 feat(tools): add the ground console with commanding and image reassembly
2026-07-29 fix(firmware): set explicit nvic priorities for the uart irqs
    [board.h, uart.c]
2026-07-29 feat(firmware): run the control cycle and sensor sampling as tasks
2026-07-29 fix(firmware): bring the console up before anything that can fault
    [fault.c, main.cpp, uart.c]
2026-07-29 feat(ground): report crc errors and make the task line readable
2026-07-30 docs: cut hardware.md down to the physical build and correct the mode bead colors
2026-07-30 docs: trim the roadmap to current state and log the documentation pass
2026-07-30 test(vv): check the requirement trace both ways automatically
2026-07-30 feat(ground): filter the telemetry stream from the console prompt
2026-07-31 feat: rfm95 and nrf24 drivers behind a shared spi lock, and the feather m0 ground station
2026-07-31 fix(comms): per-radio framing, held lora transmits, and command retransmission with duplicate protection
    [executive.cpp, main.cpp]
2026-07-31 feat(comms): downlink progress reporting, ground-station health, and a second oled panel
2026-07-31 fix(comms): pace the payload link to its receiver and drop transmit power for the bench
    [display.cpp, radios.cpp]
2026-07-31 feat(comms): selective repeat on the payload link, and image size and bearing as command arguments
2026-07-31 feat(fsw): a magnetometer-anchored absolute heading and an autonomous detumble exit
2026-07-31 refactor(ground): extract the console's protocol logic into a tested GroundSession
2026-07-31 feat(fsw): a mode clique, autonomous detumble with resume, and a self-calibrating compass
2026-07-31 feat(ground): the shoot mission macro, the untethered pass on record, and the docs caught up
2026-07-31 feat(comms): poll one telemetry frame over the beacon, and lock gyro bias only from a quiet window
2026-07-31 feat(gsw): a battery gauge on the heartbeat, honest loss-of-comms, and a panel layout pass
2026-07-31 feat(ground): a calmer console palette, tab completion for poll and shoot, and hard panel regions
2026-07-31 docs: record the battery-powered shoot run and the first over-the-air poll
2026-08-02 feat(cad): ground station plus final cad
    [Pantalla OLED 0.96'' 128x64_v1.step, ground_assembly_v6.step, ground_cover_v17.step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]
2026-08-02 docs: catch the roadmap up and log the ground station cad
2026-08-04 feat(adcs): close the attitude loop and give the wheel a way to empty itself
2026-08-04 feat(sil): report the wheel to the flight software and fit the plant to two measured coast-downs
2026-08-04 feat(ground): survey macro, breakaway sweep, recover, and a link that stays up
